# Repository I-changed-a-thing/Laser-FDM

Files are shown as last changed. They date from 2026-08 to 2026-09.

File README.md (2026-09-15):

# Laser FDM + Printer Suite

> ⚠️ **CRITICAL SAFETY & EXPERIMENTAL DISCLAIMER**:  
> This entire software project, hardware integration, and laser-assisted 3D printing pipeline are **100% EXPERIMENTAL** and provided strictly on an **AS-IS, AT-YOUR-OWN-RISK** basis.  
> **All wall smoothing modes can contain software bugs.** Specifically, **Deep Mode** and **all Wobble modes (Deep Wobble & Voxel Wobble)** still contain known bugs with complicated geometries, fine features, sharp overhangs, and non-manifold meshes.  
> High-power laser diodes introduce serious fire, permanent optical radiation (blindness), and toxic fume hazards. Never leave equipment running unattended, maintain proper ventilation, and always wear certified optical safety goggles.  
> **MANDATORY: Always inspect generated G-code in the 3D Simulator or G-Code Visualizer before printing on physical hardware!**
# ⚠️Allways where laser safty glasses⚠️

---

## What This Printer Can Do

This modified Elegoo Neptune 4 uses laser diodes to remelting and modifying the plastic dynamically during the print, it achieves features impossible on a standard printer:

* **+100% Z-Axis Strength Gain:** By pre-heating the previous layer milliseconds before new plastic is laid down (and through structural infill strategies), layer adhesion is dramatically 
* **Glossy, Glass-like Top Surfaces:** The laser does a final glazing pass to melt away top layer extrusion lines.
* **Invisible Z-Seams & Smooth Walls:** Side-mounted lasers remelt the outer perimeters, fusing layer lines together horizontally and vertically for injection-molded quality.
increased.

Here is a glimpse of the data showing the structural strength improvements (comparing standard printing vs. laser-assisted modes):

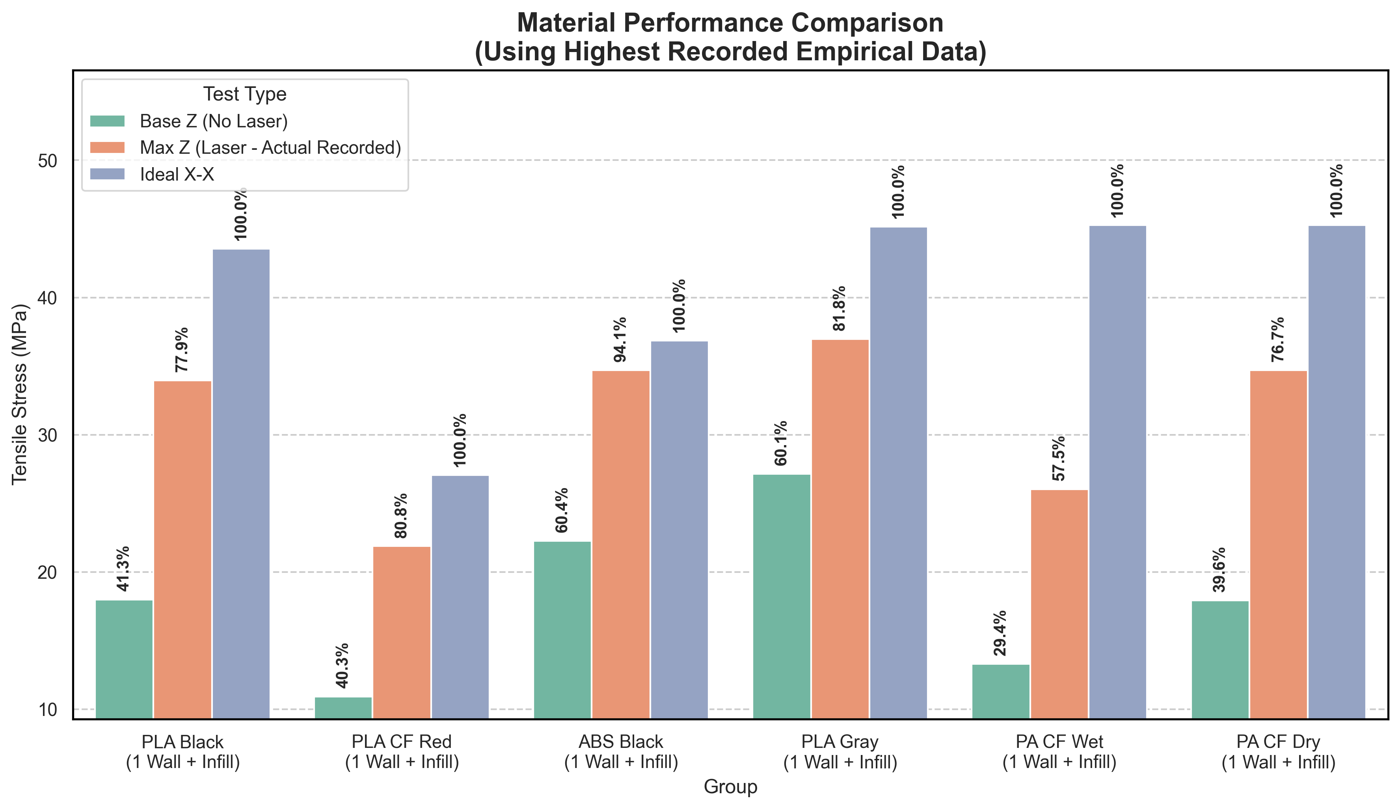
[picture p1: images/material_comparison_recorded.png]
Material Strength Comparison


---

## Video Showcases

See the Laser FDM process in action! 

### Testing Z Axis Strengths 
Testing Z Axis Strengths (https://www.youtube.com/watch?v=Z4Z035srbKI)

### Top Layer smoothing
Laser Smoothness vs Non Laser (https://www.youtube.com/watch?v=vpd5nh9Lj98)

### Wall smoothing
First look at laser FDM printing (https://www.youtube.com/watch?v=qHYnePu4Ysw)

---

## The Hardware Build

*Instructions for building your own Laser FDM printer are detailed in this open-source build guide video.*

Opensource Laser FDM (https://youtu.be/TVKNi_Bk3_o)

---

##  Software Quick Start

1. **Launch the Master Web Portal**:
   - Double-click **`index.html`** right in this folder to open the Laser 3D Printer Suite.
   - It runs completely offline with zero setup or servers required.
   - Use the **Slicer Configurator** to visually configure laser features and generate the exact OrcaSlicer post-processing command.
   
2. **Configure OrcaSlicer**:
   - In OrcaSlicer: **Print Settings** > **Others** > **Post-processing scripts**.
   - Paste the command line generated by the Configurator:
     ```text
     "your_path\python.exe" "your_path\orcaslicer_laser_advanced.py"
     ```
   - When slicing, OrcaSlicer automatically calls the script to inject synchronized laser commands.
   - Use the **G-Code Visualizer** or **3D Toolhead Simulator** to inspect toolpaths layer-by-layer before sending them to your machine.

3. **Printer Firmware (`printer.cfg`)**:
   - Contains reference Klipper output pins (`laser_pwm1`, `laser_pwm2`, `laser_pwm3`) and safety interlocks.

---

## 📂 Release Folder Contents

* **`index.html`**: The main launcher & portal (highest level). Open this in any browser!
* **`web_tools/`**: All web applications:
  * **`configurator/index.html`**: Parameter generator for orcaslicer_laser_advanced.py in Orcalsicer.
  * **`gcode_visualizer/`**: Fast 2D/3D toolpath inspector tool for g-code.
  * **`simulator_3d/`**: G-code toolpath simulation with power heatmaps.
  * **`calibration/index.html`**: Step-by-step guild to calibration wall smoothing offsets.
* **`orcaslicer_laser_advanced.py`**: Production post-processing script for preheating, top surface smoothing, and wall smoothing.
* **`orcaslicer_bricklayer_infill.py`**: Bricklayer infill generator.
* **`orcaslicer_vibrate_infill.py`**: Z-axis infill wave generator script.
* **`printer.cfg`**: Reference Klipper configuration for laser PWM pins.
* **`User_Guide.md`**: Detailed operational guide explaining every single parameter.
* **`Technical_Documentation.md`**: Comprehensive technical architecture and function documentation.

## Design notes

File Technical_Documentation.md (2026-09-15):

# Laser 3D Printer - Technical Documentation

This document provides a comprehensive technical overview of the Laser 3D Printer software stack. It details how the different software components interact, the architecture of the post-processing pipeline, and in-depth descriptions of the functions within each Python script.

---

## 1. System Architecture Overview

The software stack integrates laser processing directly into a standard FDM 3D printing workflow. It intercepts the sliced G-code before it reaches the printer, analyzes the geometric paths (e.g., top surfaces, outer walls), and dynamically injects precise laser control commands. 

The architecture consists of four primary components:
1. **Web Generator UI (`web_generator/index.html`)**: A frontend application that acts as the control panel. Users define their parameters visually, and the UI generates a long, complex command-line string.
2. **OrcaSlicer Post-Processing**: The generated command-line string is pasted into OrcaSlicer's post-processing settings. When a model is sliced, OrcaSlicer automatically runs the Python scripts on the output `.gcode` file.
3. **Python Processing Scripts**: The scripts parse the G-code line-by-line, calculate vectors, cluster geometric shapes, and generate new G-code commands (e.g., `SET_PIN PIN=laser_pwm VALUE=...`) based on the requested features (annealing, smoothing, etc.).
4. **Klipper Firmware (`printer.cfg`)**: The printer's firmware receives the modified G-code. Custom macros and `[output_pin]` configurations execute the laser commands synchronously with the toolhead movements.

---

> ⚠️ **DEVELOPMENT STATUS**: Standard horizontal wall smoothing is the stable production method. All advanced multi-layer wall modes (Deep, Wobble, Voxel Wobble, Voxel Raycast) are in **ALPHA** and must be visually verified before printing on physical hardware.

## 2. Core Post-Processing Script
### `orcaslicer_laser_advanced.py`

This is the primary script responsible for analyzing the G-code and injecting laser commands for preheating, annealing, smoothing, wall remelting. It heavily utilizes 2D vector mathematics and spatial clustering.

#### Geometric & Mathematical Helpers
- **`get_val(line, char)`**: Parses a G-code line (e.g., `G1 X100 Y50 E2 F3000`) and extracts the numeric value following a specific character (e.g., `X`). Returns `None` if missing.
- **`compute_rotated_bbox(points, angle_deg=0.0, margin=0.0)`**: Calculates a rotated bounding box for a set of 2D points to align laser raster paths accurately across irregularly shaped surfaces.
- **`is_touching(ptsA, ptsB, max_dist=3.0)`**: Determines if two sets of points are close enough to be considered a single contiguous shape.
- **`downsample_points(points, resolution=0.5)`**: Reduces the number of points in a path to optimize computation speed.
- **`cluster_points(points, max_dist=2.5)`**: Groups a large set of points into individual, spatially isolated clusters (representing distinct islands or parts on the build plate).
- **`bbox_area(bbox)`**: Calculates the area in mm² of a bounding box.
- **`calculate_boosted_power(base_power, area)`**: Dynamically increases laser power for larger surface areas where heat dissipates more rapidly.

#### Raster & Grid Generation
- **`build_boolean_grid(points, res, max_dist)`**: Creates a 2D boolean occupation grid representing solid areas vs. empty space, used to ensure the laser only fires over the actual printed part and not thin air.
- **`generate_laser_grid(...)`**: The core rasterization engine. It takes a bounding box, an angle, and physical parameters to generate a dense zig-zag pattern of G-code moves across a surface. It handles clipping against the boolean grid, alternating directions, and inserting precise `SET_PIN` commands.
- **`generate_laser_connectivity(...)`**: Similar to the laser grid, but optimized for generating distinct conductive or structural traces.

#### Wall & Path Smoothing
- **`is_point_in_path(pt_x, pt_y, path)`**: Uses ray-casting to determine if a specific point lies inside a closed polygon (used for inner/outer wall sorting).
- **`build_paths_from_segments(segments)`**: Takes chaotic, disconnected line segments and stitches them into continuous, ordered polygons.
- **`split_corners_in_paths(paths, corner_dist, power_scaler, ...)`**: Analyzes paths for sharp corners/angles and dynamically reduces laser power at the apex to prevent overheating and melting the corner away.
- **`generate_wall_smooth_passes(...)`**: Processes outer wall polygons. It calculates perpendicular offsets to position the side-mounted lasers exactly at the focal distance, and handles Z-axis interlacing, multi-height divisions, and temperature drops.
- **`generate_voxel_wobble_passes(...)` & `generate_voxel_raycast_wall_passes(...)`**: Modern slope-adaptive 3D wall smoothing engines. They compute perpendicular offsets, analyze layer-to-layer slope vectors, and apply dynamic apex displacement to follow outer perimeters smoothly.
- **`check_3d_sloped_occlusion(...)`**: Raycasting function that uses the physical diode laser elevation angle (e.g. 22°) to verify line-of-sight and prevent firing through intervening geometry.
- **`generate_wobble_passes(...)`**: Generates high-frequency sinusoidal oscillations along the wall path to broaden the laser melt pool without excessive heat concentration.

#### Parsing & Extraction
- **`will_laser_resume_shortly(...)`**: A look-ahead function that checks upcoming G-code lines to see if the laser will be needed again immediately, preventing unnecessary on/off cycling.
- **`extract_outer_walls(lines)`** & **`extract_top_surfaces(lines)`**: Specialized parsers that scan the raw OrcaSlicer output and extract the exact X/Y coordinates of walls and top layers based on slicing comments.
- **`process_gcode(file_path, args)`**: The main execution loop. It reads the file, tracks the current state (X, Y, Z, E, Feedrate), maintains the active laser configuration, delegates generation to the functions above, and writes the final modified file back to disk.

---

## 3. Mechanical & Infill Manipulation

### `orcaslicer_bricklayer_infill.py`
This script alters internal infill geometry to create staggered, interlocking "brick" patterns that improve structural integrity.
- **`get_val(line, key)`**: G-code parsing helper.
- **`strip_z(line)`**: Removes Z-axis moves from a line to normalize 2D logic.
- **`process_gcode(...)`**: Scans for infill lines and injects retractions and Z-hops to break continuous extrusions into distinct structural "bricks".

### `orcaslicer_vibrate_infill.py`
This script introduces vertical Z-axis oscillations during infill printing to create a 3D corrugated internal structure for enhanced Z-axis strength.
- **`smooth_envelope(d, fade, L)`**: Calculates a mathematical fade-in/fade-out envelope so that the vibrations taper off smoothly near the walls, preventing nozzle collisions with solid perimeters.
- **`process_gcode(...)`**: The main execution loop. It breaks long, flat infill lines into hundreds of microscopic segments, modulating the Z-height of each segment based on a sine wave function `sin(distance / wavelength) * amplitude * envelope`.

---

## 4. Web Ecosystem

### Unified Web Suite (`index.html`)
The release features a unified, responsive Web Suite that runs entirely offline with zero server requirements. A master Hub connects four specialized subpages with persistent cross-navigation:
1. **Configurator & Calibration (`web_tools/configurator/`)**: Generates OrcaSlicer CLI strings, includes JSON preset export/import, Virtual PCB parameters, experimental slicing paths, and Matrix calibration.
2. **G-Code Visualizer (`web_tools/gcode_visualizer/`)**: Fast 2D/3D toolpath inspector with support for hardware Calibration Levels (0 to 4), power heatmaps, and chunk analysis.
3. **3D Toolhead Simulator (`web_tools/simulator_3d/`)**: Photorealistic WebGL simulation featuring the authentic 3D CAD toolhead assembly, cooling fans, golden nozzle, and macro melt-zone camera.
4. **Offset Calibration (`web_tools/calibration/`)**: Step-by-step 10mm cube paper calibration to align angled laser diodes and generate Klipper test macros.
The frontend is built using standard HTML/CSS/JS. It relies on a JavaScript function `generateCommand()` that triggers on any input change. This function dynamically reads all DOM elements, checks for active toggles, and concatenates a formatted string of Python CLI arguments. The UI leverages `localStorage` to save settings between sessions, and implements `JSON.parse`/`JSON.stringify` to export/import complete material preset profiles to the local disk.

### 3D Visualizer (`web_tools/gcode_visualizer/index.html`)
The visualizer uses **Three.js** to render G-code paths in a web browser. It parses standard `G1` moves into lines. More importantly, it specifically searches for the injected `SET_PIN PIN=laser_pwm...` commands generated by the Python scripts. When it detects a laser activation, it changes the color and thickness of the rendered path, interpolating colors from blue (low power) to red (high power), allowing users to visually verify the laser paths and calibration sweeps before running the print.

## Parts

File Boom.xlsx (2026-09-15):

BOM
Part | Link | units | Usecase
Laser Safety glasses for 450nm |  | 1 | To be safe from the lasers
Laser | https://a.aliexpress.com/_EHrgeaE | 2 to 3 | 2 lasers for premelting and 1 for top surface smoothing
ABS | https://www.aliexpress.com/item/1005004961613582.html | 200 g | Material for the Laser holder
12 V 15 A Power supply | https://a.aliexpress.com/_EuvEg3G | 1 | Power the lasers
M2 screws | https://aliexpress.com/item/1005007299422418.html | 4 | Screw in the laser holder into printhead
M3 screws | https://aliexpress.com/item/1005007299422418.html | 12 | Screw in the printer fans
4015 blower fan | https://www.aliexpress.com/item/1005011635639684.html | 1 | Replaces the old small hotend fan
pin connector female | https://a.aliexpress.com/_EjI898i | 3 | Connect the laser to the 3d printer bord pins
Spare cables |  | 3 m | Spare cables to exstand laser lenght

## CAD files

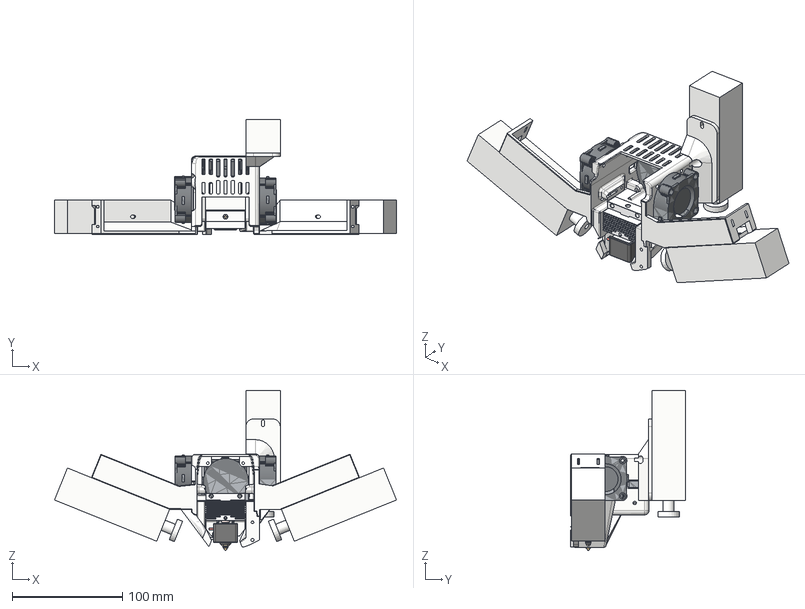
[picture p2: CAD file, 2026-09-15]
CAD/Laser holder.step
310.3 x 103.9 x 145.5 mm
Elegoo Neptune 4 Pro Hotend
PROX2_5_001 (Solid) x 3
Laser 3
Laser x+
Laser x-

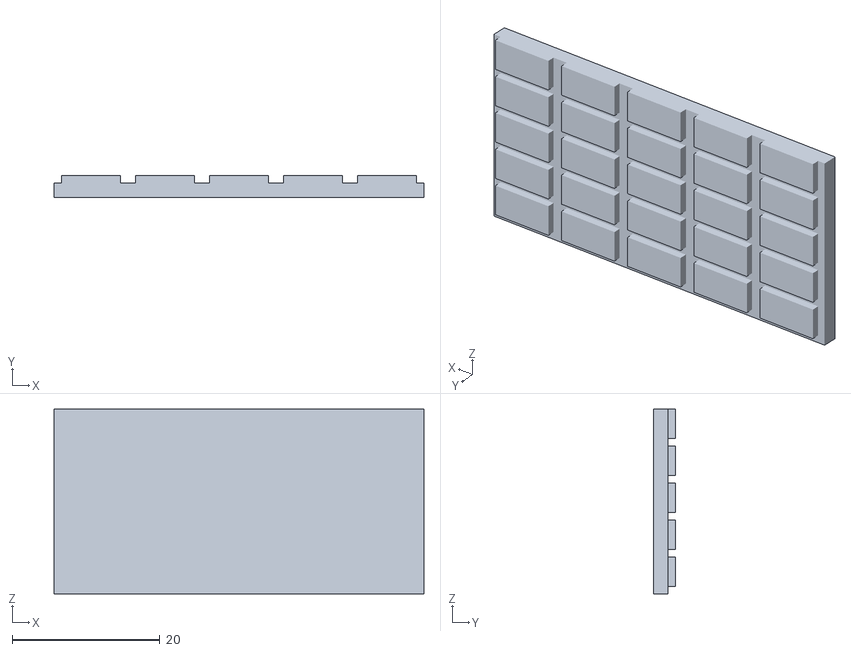
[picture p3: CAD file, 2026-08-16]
Matrix calibration stls/Matrix_Wall_Smoothing.stl
50.0 x 3.00 x 25.0

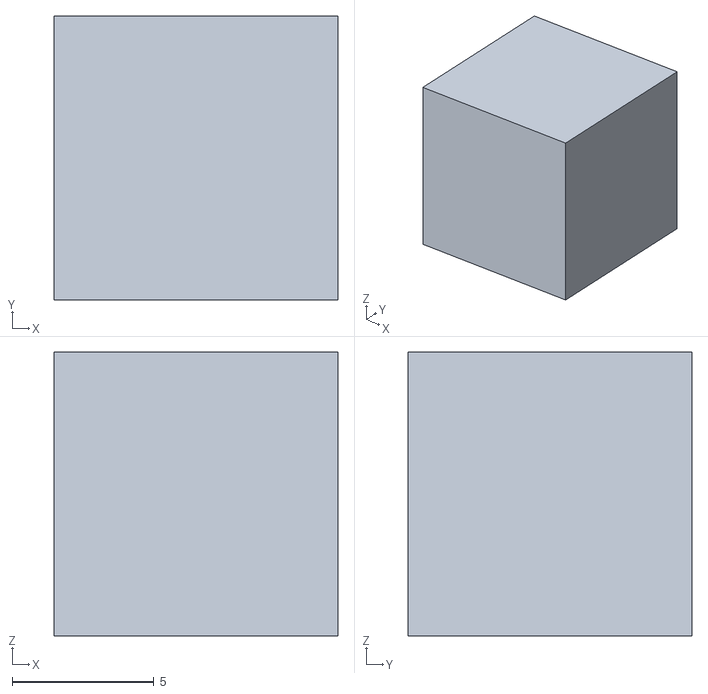
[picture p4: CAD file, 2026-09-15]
web_tools/calibration/models/calibration_cube_10mm.stl
10.0 x 10.0 x 10.0

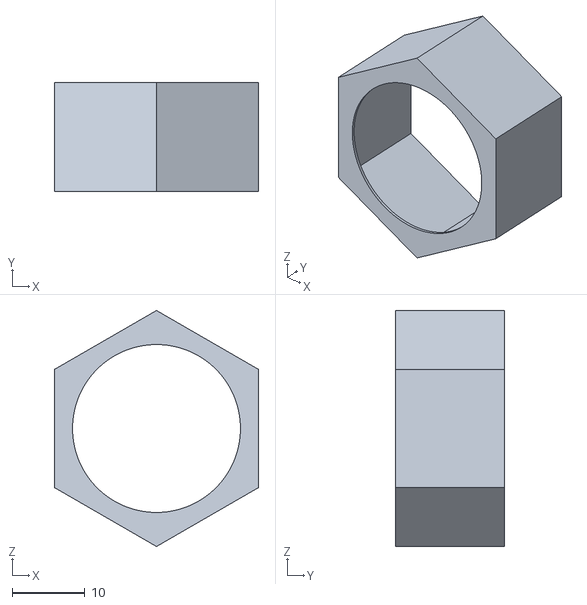
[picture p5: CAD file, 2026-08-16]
Matrix calibration stls/six edege smoothing test.stl
28.0 x 15.0 x 32.3

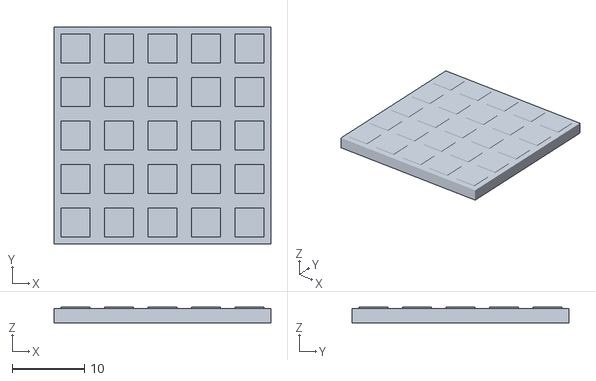
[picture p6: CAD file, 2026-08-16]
Matrix calibration stls/Matrix_Top_Smoothing.stl
30.0 x 30.0 x 2.20

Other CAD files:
CAD/Laser holder.stl

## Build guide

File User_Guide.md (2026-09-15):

# Laser 3D Printer - User Guide

> ⚠️ **IMPORTANT SAFETY & EXPERIMENTAL NOTICE**:  
> The Laser 3D Printer software and hardware stack is **100% EXPERIMENTAL**. All operations are strictly at your own risk.  
> **All wall smoothing modes can contain bugs.** In particular, **Deep Mode** and all **Wobble modes (Deep Wobble & Voxel Wobble)** still have known bugs on complicated shapes, acute overhangs, and fine geometric features.  
> **Always inspect toolpaths in the G-Code Visualizer or 3D Simulator before printing!**

Welcome to the Laser 3D Printer User Guide! This manual explains all the features available in the software, what they actually do to your 3D print, and what every single setting changes so you can get the most out of the script.

---

## 1. Top Surface Smoothing
**What it does:** Once your printer finishes the top layers of a part, it lifts the nozzle slightly and uses a laser to trace a zig-zag pattern over the surface. The heat from the laser gently melts the top layer, reflowing the plastic into a perfectly smooth, glossy finish that hides all extrusion lines.

**Settings:**
*   **Enable:** Turns the feature on or off.
*   **Power:** How strong the laser fires (PWM percentage). Too high causes boiling; too low won't melt the surface.
*   **Speed:** How fast the toolhead moves in mm/s. Slower speeds allow heat to soak deeper.
*   **Grid Spacing:** The distance between the laser zig-zag lines. A smaller spacing (e.g., `0.2mm`) ensures no gaps are left un-melted, but takes longer to print.
*   **Z-Hop:** Lifts the nozzle (e.g., `0.5mm`) so it doesn't drag through the freshly melted plastic while the laser is running.
*   **Overshoot:** The laser will run slightly past the edge of the part before turning around. This prevents the laser from lingering at the edges while the printer decelerates, avoiding burnt corners.
*   **Overshoot Without Laser:** Turns the laser off during the overshoot move so it doesn't fire into thin air.
*   **Passes:** How many times the laser traces the entire surface.
*   **No Alternate:** By default, each pass rotates the zig-zag direction. Enabling this forces all passes to run in the exact same direction.
*   **Angle:** The starting angle (in degrees) of the laser zig-zag pattern.
*   **Angle Step:** How many degrees the pattern rotates on each subsequent pass (default is 90 degrees, creating a crosshatch pattern).
*   **Fan Speed:** Forces the part cooling fan to a specific speed (0-255) during smoothing to cool the plastic immediately after melting.
*   **Preheat Delay:** Forces the laser to turn on and wait in one spot for a few milliseconds before moving, ensuring the start of the line melts properly.
*   **Group Slopes:** Tries to group slanted top surfaces together for smoother continuous sweeps.
*   **Smart Chunking:** If a top surface is too massive, the plastic might warp. This breaks large flat surfaces into smaller "chunks" (e.g., 20mm squares) and smooths them one by one.
*   **Chunk Size:** The maximum size of the chunks in mm.
*   **Chunk No Full Pass:** Disables the final "blending" pass that usually runs over the entire surface to hide the seams between chunks.
*   **Chunk Full Pass Power:** The specific laser power used for that final blending pass.
*   **Area Boost:** Automatically increases laser power on massive surfaces because large areas dissipate heat much faster than tiny spots.
*   **Area Boost (Multiplier):** How much extra power to add at maximum boost (e.g., `0.6` = +60%).
*   **Area Max:** The maximum size (mm²) where the boost hits its ceiling.
*   **Area Base:** The size (mm²) where the script begins gradually applying the boost.

---

## 2. Wall Smoothing
> ⚠️ **IMPORTANT ALPHA NOTICE**:  
> **Standard (Horizontal) mode** is the primary, stable wall remelting technique.  
> All vertical multi-layer modes (**Deep Mode**, **Deep Wobble**, and **Voxel Wobble**) are currently in **ALPHA**. Because they compute complex 3D sweeps across varying layer heights and overhang angles, they are experimental and likely to contain bugs on intricate geometries.  
> **Always inspect your G-code in the G-Code Visualizer or 3D Simulator before printing!**

**What it does:** Layer lines on vertical walls can be unsightly. Wall Smoothing activates side-mounted lasers to trace the outer perimeter of your print, remelting the sides and fusing the layer lines together into a single, smooth surface.

**Settings:**
*   **Enable:** Turns the feature on or off.
*   **Wall Offset Level:** A quick preset to tell the script the X and Z offset distances of your side-mounted lasers.
*   **Custom X+ / X- / Z Offsets:** Exact physical distance from your nozzle to the laser focal point, overriding the level preset.
*   **Power X+ / Power X-:** The laser power for the left and right side lasers.
*   **Overhang Power X+ / X-:** Specific power settings used only when the wall leans outward (an overhang), as they require less power to melt.
*   **Speed:** How fast the toolhead moves along the wall.
*   **Passes:** Number of times the laser traces the wall on a single layer.
*   **Wall Frequency (Layers):** Instead of running every single layer, you can tell it to run every N layers (e.g., every 3 layers).
*   **Target (Both, Inner, Outer):** Which perimeters to smooth. Usually you only want `Outer`.
*   **Min Path Area:** Skips tiny loops (like small bolt holes) where the laser would just sit and burn the plastic.
*   **Angle Tolerance:** Skips walls that lean beyond this angle (aggressive overhangs) to prevent them from drooping.
*   **Corner Power Drop:** Reduces laser power at sharp corners to prevent them from rounding off or melting away.
*   **Corner Distance:** How far from the apex of the corner the power drop begins.
*   **Overshoot:** Extends the wall trace slightly past the start point to ensure the seam is fully melted.
*   **Retract / Max Retract:** Retracts the filament inside the nozzle so it doesn't ooze out while the laser is smoothing the wall.
*   **Standby Temp Drop:** Lowers the hotend temperature temporarily while performing long smoothing operations to prevent filament degradation.
*   **Deep Mode:** Instead of tracing horizontally, the laser pauses and sweeps vertically up and down across multiple layers, deeply fusing a thick vertical chunk.
*   **Z-Divisions:** How many vertical slices to make during Deep Mode.
*   **Deep Overhang Angle:** A stricter angle tolerance for Deep Mode.
*   **Deep Overlap:** How many layers to overlap the vertical sweeps so horizontal seams don't form between chunks.
*   **Deep Safety / Max Layer Safety:** Leaves the very top layers untouched by the deep sweep so the nozzle doesn't collide with them later.
*   **Deep Bottom Up:** Reverses the sweep to start from the bottom and move upward.
*   **Deep Interlace:** Staggers the vertical sweeps to prevent heat from building up in one spot.
*   **Deep Delay Passes:** Waits until the whole wall is done before starting the second pass to allow cooling.
*   **Deep Fade:** Tapers off the power at the very end of a deep sweep to leave a pristine finish.
*   **Wobble Mode:** Rapidly wiggles the laser left/right as it moves along the wall to artificially widen the melt zone without increasing power.
*   **Wobble Projection Factor:** How wide the wiggle should be.
*   **Wobble Pull Only:** Forces the wobble to only happen in directions moving away from the nozzle to prevent crashing into fresh plastic.
*   **Wobble Pull Continuous:** Smooths out the zig-zag into a more continuous wave.
*   **Deep Wobble / Seam Wobble:** Special parameters combining deep vertical sweeps with high-frequency horizontal wiggling for maximum blending.
*   **Pass 2 Mode:** Allows you to run a second, entirely different smoothing strategy immediately after the first pass finishes.
*   **Pass 1 & Pass 2 Modes:**
    *   `Standard`: Traces horizontally along the current layer's outer perimeter (Stable).
    *   `Deep Mode`: Sweeps vertically across multiple layers (Alpha).
    *   `Deep Wobble`: Combines vertical sweeps with horizontal zig-zag oscillation (Alpha).
    *   `Voxel Wobble`: Dynamic slope-adaptive 3D oscillation that follows sloping contours (Alpha).
*   **Wobble X-Scale:** Multiplier to scale the horizontal sweep amplitude to compensate for diode laser beam defocusing.
*   **Adaptive Slope Compensation:** Dynamically shifts the wobble apex outward or inward to match underlying layer overhang angles.
*   **Smart Island Chunking:** Detects when small islands or discrete features end early, triggering smoothing immediately rather than waiting for the entire block.

---

## 3. Experimental Slicing Paths (Bricklayer & Vibration)
**What it does:** Specialized kinematic post-processing tools that operate directly on G-code extrusion and Z movements without firing laser diodes.
## 3. Structural Infill (Bricklayer & Vibration)
**What it does:** Specialized kinematic post-processing tools that operate directly on G-code extrusion and Z movements without firing laser diodes. They alter how your internal infill is printed to make parts stronger.

### Bricklayer Infill (`orcaslicer_bricklayer_infill.py`)
* **Interlocking Extrusion Paths:** Transforms standard 2D infill rasters into a staggered, brick-and-mortar 3D interlock. This dramatically enhances layer-to-layer shear strength and reduces delamination.
Transforms standard 2D infill rasters into a staggered, brick-and-mortar 3D interlock to stop cracks from propagating cleanly through the part.
* **Extrusion Multiplier:** Adjusts flow during bricklaying passes.
* **Retract Length & Z-Hop:** Prevents stringing and collisions during injected travel moves.
* **Retract Length / Speed:** Defines the retraction pulling the filament back between bricks.
* **Z-Hop:** Lifts the nozzle between bricks to prevent stringing.

### Z-Axis Vibration (`orcaslicer_vibrate_infill.py`)
* **Sinusoidal Infill Corrugation:** Oscillates the Z-axis in a fine sinusoidal wave pattern along infill lines. Corrugated vertical ribs create massive structural stiffness while conserving material.
* **Amplitude & Wavelength:** Controls wave height and spacing between peaks.
* **Fade Distance:** Flattens waves near perimeter walls to preserve dimensional accuracy.
Oscillates the Z-axis in a fine sinusoidal wave pattern along infill lines. Corrugated vertical ribs create massive structural stiffness while conserving material.
* **Amplitude:** How high the waves go in mm.
* **Wavelength:** How stretched out the waves are in mm.
* **Spacing:** Distance between parallel lines.
* **Fade Distance:** Flattens waves near perimeter walls to preserve dimensional accuracy and prevent nozzle crashes.
* **Resolution:** How many microscopic segments the straight lines are broken into to create the wave.
* **Sync Phase:** Forces all waves to align perfectly with each other across different lines.

## 4. Preheating
**What it does:** Normally, hot plastic is laid down onto cold plastic, leading to weak bonds. Preheating solves this by firing a laser slightly ahead of the moving nozzle. It pre-melts the surface just milliseconds before the fresh plastic is extruded on top of it, resulting in incredible inter-layer adhesion.

**Settings:**
*   **Enable:** Turns the feature on or off.
*   **Preheat Power:** The base power used. Too high and the plastic will boil.
*   **Reference Speed:** The script automatically scales the laser power based on how fast the toolhead is currently moving. You set the "Reference Speed" (e.g., 50mm/s), and the script calculates everything relative to that.
*   **Min Laser Power:** Hardware minimum limit. If the calculated power drops below this, the laser turns off completely instead of sputtering.
*   **Min Layer:** Skips preheating on the very first few layers.
*   **Trailing Enable:** Activates a second laser located *behind* the nozzle to post-heat the line after it's extruded.
*   **Trailing Ratio:** How strong the trailing laser should be compared to the main preheat laser (e.g., 0.5 = 50% strength).

---

## 5. Annealing
**What it does:** After a layer finishes printing, the laser does a very fast, low-power zig-zag pass over the entire layer. This doesn't melt the plastic, but keeps it warm (in its "crystallization window"). This reduces internal stress, prevents warping, and increases structural strength.

**Settings:**
*   **Enable:** Turns the feature on or off.
*   **Anneal Power:** Must be kept very low. You only want to warm the plastic, not melt it.
*   **Speed:** Usually kept relatively fast to distribute heat evenly.
*   **Spacing:** Distance between the zig-zag lines.
*   **Z-Hop:** Lifts the nozzle so it doesn't drag across the layer.
*   **Overshoot / Overshoot Without Laser:** Extends the path past the edge of the part, optionally turning the laser off during the turn to prevent edge burning.
*   **Min Layer:** Skips annealing on the bottom layers since the heated bed already keeps them warm.
*   **Margin:** Shrinks the annealing path inward from the edge.
*   **Min Area:** Skips annealing on tiny islands.
*   **Angle:** The direction of the annealing zig-zag path.

---

## 6. Structural Infill (Vibration & Bricklayer)
These are special non-laser scripts that alter how your internal infill is printed to make parts stronger.

*   **Z-Axis Vibration:** Rapidly shakes the nozzle up and down while printing infill lines to create corrugated, 3D wave structures inside your part.
    *   **Amplitude:** How high the waves go in mm.
    *   **Wavelength:** How stretched out the waves are in mm.
    *   **Spacing:** Distance between parallel lines.
    *   **Fade:** Gradually flattens the waves near the outer walls so the nozzle doesn't crash into solid perimeters.
    *   **Resolution:** How many microscopic segments the straight lines are broken into to create the wave.
    *   **Sync Phase:** Forces all waves to align perfectly with each other across different lines.

*   **Bricklayer:** Breaks continuous infill lines into staggered, interlocking "bricks" to stop cracks from propagating cleanly through the part.
    *   **Extrusion Multiplier:** Adjusts flow rate for the bricks.
    *   **Retract Length / Speed:** Defines the retraction pulling the filament back between bricks.
    *   **Z-Hop:** Lifts the nozzle between bricks to prevent stringing.

---

## 5. Virtual PCB & Cable Maker Mode
## 6. Virtual PCB & Cable Maker Mode
**What it does:** Allows standard 3D printers to fabricate embedded conductive traces by selectively pyrolyzing and graphitizing carbon-loaded or polymer filaments with the laser diode.

**Settings:**
*   **Enable 2-Pass Mode (`--two-pass`):**
    *   **Pass 1 (Carbonize):** High-energy laser pass to break polymer chains and leave a carbon-rich conductive path.
    *   **Pass 2 (Graphitize / Anneal):** Lower-power, slower secondary pass that crystallizes/graphitizes the carbon path to dramatically reduce electrical resistance.
*   **Pass 1 Power / Speed:** Laser PWM and toolhead speed for initial carbonization.
*   **Pass 2 Power / Speed:** Laser PWM and toolhead speed for the graphitizing annealing pass.
*   **Offset X / Y:** Precise optical offsets from the nozzle tip to the laser focal spot for trace drawing.

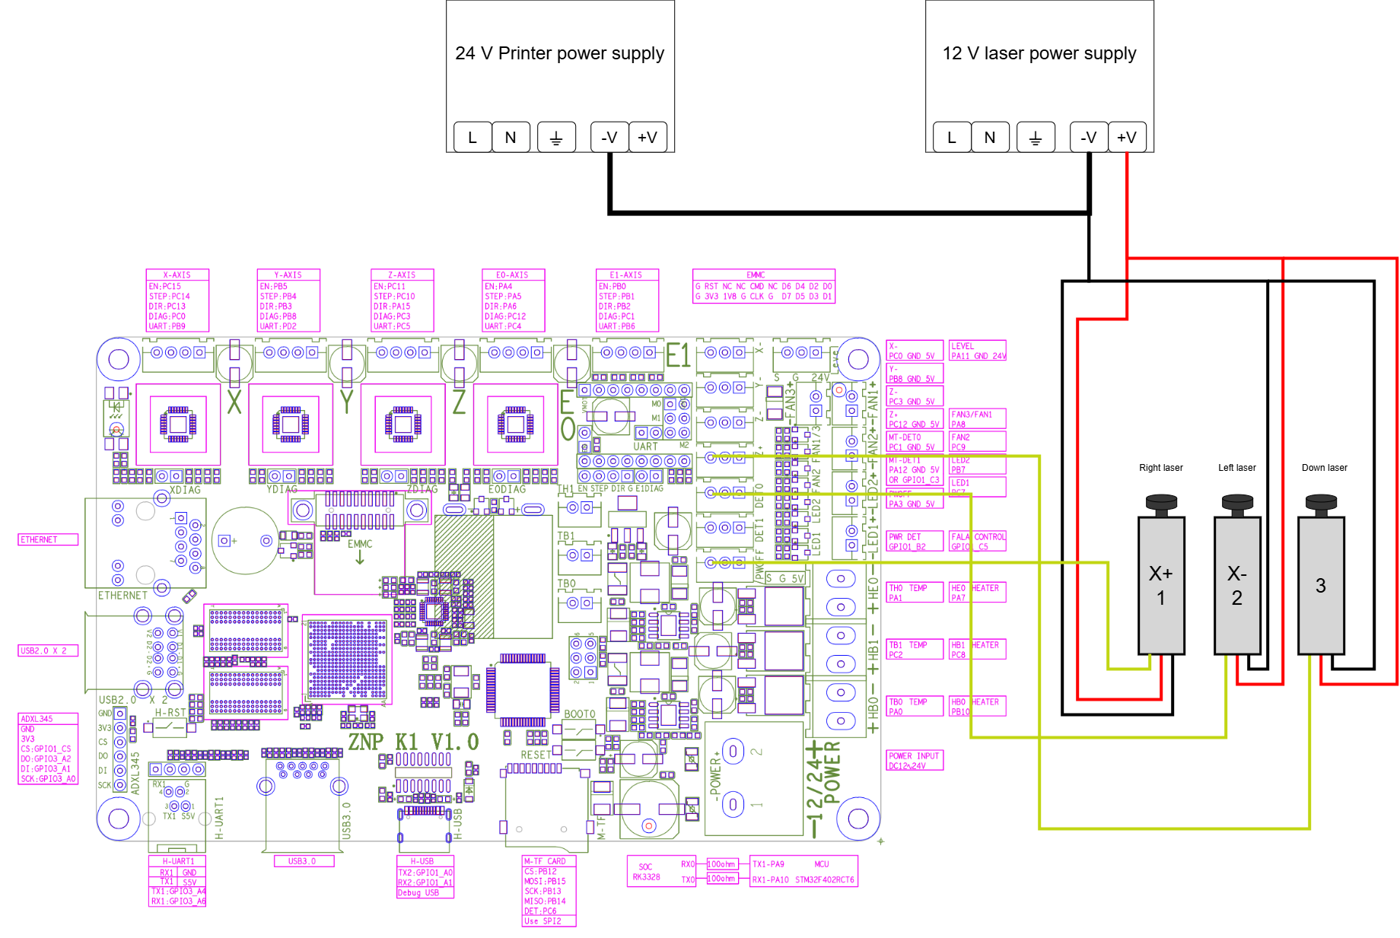
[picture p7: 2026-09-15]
Drawings/Wiring Laser FDM.png

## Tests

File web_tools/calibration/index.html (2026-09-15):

# Laser Diode Offset Calibration

# Laser Wall Offset Calibration

Mounting tolerances can slightly change the true angle of the lasers, which is why we must calibrate them for every machine individually and per laser. Higher offsets might be better for bigger parts to get larger chunk sizes working, though it results in a more defocused beam.

Uncalibrated No default offsets are shipped for safety reasons. Please calibrate the 5 fixed Z standoff heights below.

Download Config File

### Laser Calibration Table

Find your X offsets (Laser 1 and Laser 2) across the 5 default Z heights, or set your own custom height.

Level | Z Standoff | Laser 1 X+ (mm) | Laser 2 X- (mm) | Status

Safety Note: Custom Z standoff must be strictly positive (Z > 0 mm). Zero or negative Z heights are rejected to prevent toolhead collisions.

Save to Browser Hard-Save Config (JSON) Load Config File

Reset / Clear

### Step-by-Step Visual Showcase

Interactive cross-section showing nozzle, paper, 10mm cube, and laser alignment at each step.

Laser 1 (X+) Laser 2 (X-)

1 Print & Remove 2 Home Printer 3 Place Cube 4 Find Z Baseline 5 Align Edge 6 Select Laser 7 Move Z Up 8 Find Offset 9 Save Values

### Calibration Steps

Download 10mm Cube STL

1

#### Print & Remove 10mm Cube

Print the 10x10x10 mm cube. Once done, remove the cube from the bed! Do not home the printer while the cube is on the bed.

2

#### Home Printer (Empty Bed)

Use your printer's menu to home all axes while the bed is completely empty. This ensures the printer finds its zero safely.

3

#### Place Cube Under Nozzle

Move the toolhead up so you can safely place the 10mm cube back onto the bed, directly under the nozzle.

4

#### Find Z Baseline

Place a piece of paper on the cube. Use the printer's menu to slowly lower the nozzle until you feel light friction on the paper. Remove the paper. This is your Z baseline height.

5

#### Align Nozzle to Cube Edge

Move the toolhead using the printer menu until the nozzle tip is perfectly flush with the outer vertical edge of the cube. This position is your X baseline.

6

#### Select Laser & Height

Decide which laser to calibrate first: Laser 1 (Right) or Laser 2 (Left). Choose a Z standoff height from the table (e.g., Level 2 at 10mm).

7

#### Move Z Up & Turn on Laser

Using the printer's menu, move the Z axis up by your chosen standoff height (e.g., move up 10mm). Then, run your printer's laser test macro to turn on the laser at a safe, low power.

8

#### Find the X Offset

Move the toolhead sideways (along the X axis) until the laser spot hits the vertical side wall of the cube. You need to align it so that the exact center of the laser spot rests perfectly on the center of the top layer on that side wall, not the absolute top edge of the part. Note down the distance you moved from your X baseline.

Show Good Alignment Show Bad Alignment

10mm Cube Wall

Correct: The exact center of the laser spot perfectly aligns with the center of the top layer (the middle of the layer's thickness).

9

#### Save Your Values

Enter the X distance into the table. Repeat this entire process for the other laser and for all the standoff heights you want to calibrate. Click Save to Browser and then Hard-Save Config (JSON).

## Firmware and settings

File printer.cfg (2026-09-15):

####################################################################################
# Machine type: NEPTUNE 4
# Current configuration version: V1.4
# Date：2023-12-1
####################################################################################
# This product (Neptune 4/4pro/4plus/4max) adopts Klipper firmware 
# and does not support users to update the official klipper/fluidd
# /moonraker by themselves, otherwise the machine will not work properly.
# If you want to DIY and are an expert or interested in this field, 
# we recommend that you prepare your own tools for burning images so 
# that you can restore them if problems arise. Please contact after-sales 
# support team for tutorials on burning images. Thank you for your cooperation!
####################################################################################
# This file contains common pin mappings for ZNP-K1-V1.0 
# boards. To use this config, the firmware should be compiled for the
# STM32F402. When running "make menuconfig", enable "extra low-level
# configuration setup", select the 32KiB bootloader, and serial (on
# USART1 PA10/PA9) communication.

# The "make flash" command does not work on the ZN-K1-V1.0. Instead,
# after running "make", copy the generated "out/klipper.bin" file to a
# file named "elegoo_k1.bin" on an SD card and then restart the ZNP-K1-V1.0
# with that SD card.

# See docs/Config_Reference.md for a description of parameters.
####################################################################################


[include plr.cfg]

[mcu]
# The hardware use USART1 PA10/PA9 connect to RK3328
serial: /dev/ttyS0
restart_method: command

[stepper_x]
step_pin:PC14
dir_pin:PC13
enable_pin:!PC15
microsteps: 16
rotation_distance: 40
full_steps_per_rotation:200  #set to 400 for 0.9 degree stepper
endstop_pin:PC0
position_min: -6  
position_endstop:-4
position_max: 235
homing_speed:50
homing_retract_dist:5
homing_positive_dir:false

[stepper_y]
step_pin:PB4
dir_pin:PB3
enable_pin:!PB5
microsteps:16
rotation_distance: 40
full_steps_per_rotation:200  #set to 400 for 0.9 degree stepper
endstop_pin:PB8
position_min: -2
position_endstop:0 
position_max:235
homing_speed:50
homing_retract_dist:5
homing_positive_dir:false


[stepper_z]
step_pin:PC10
dir_pin:!PA15
enable_pin: !PC11
microsteps: 16
rotation_distance: 8
full_steps_per_rotation: 200
endstop_pin:probe:z_virtual_endstop ## PB12 for Z-max; endstop have'!' is NO

##  Z-position of nozzle (in mm) to z-endstop trigger point relative to print surface (Z0)
##  (+) value = endstop above Z0, (-) value = endstop below
##	Increasing position_endstop brings nozzle closer to the bed
##  After you run Z_ENDSTOP_CALIBRATE, position_endstop will be stored at the very end of your config
#position_endstop:-5
position_max: 268
position_min: -5 
homing_speed: 8
homing_retract_dist: 5
second_homing_speed: 3

[extruder]
step_pin:PA5
dir_pin:!PA6
enable_pin:!PA4
microsteps:16
rotation_distance: 28.7086  #31.4	#Bondtech 5mm Drive Gears
gear_ratio: 52:10
full_steps_per_rotation: 200	#200 for 1.8 degree, 400 for 0.9 degree
nozzle_diameter: 0.400
filament_diameter: 1.750
min_temp: 0
max_temp: 330
heater_pin: PA7
sensor_type:NTC 100K MGB18-104F39050L32
sensor_pin: PA1
max_power: 1
#control :pid
#pid_kp : 26.213
#pid_ki : 1.304
#pid_kd : 131.721
pressure_advance: 0.020
pressure_advance_smooth_time: 0.01
instantaneous_corner_velocity: 2.5
max_extrude_only_distance: 300
max_extrude_only_velocity:60
max_extrude_only_accel:5000
max_extrude_cross_section: 99
min_extrude_temp:100

[verify_heater extruder]
max_error: 120
check_gain_time:30
hysteresis: 10
heating_gain: 2

[heater_bed]
heater_pin:PB10
sensor_type: NTC 100K MGB18-104F39050L32
sensor_pin: PA0
max_power: 1.0
#control = watermark
min_temp: 0
max_temp: 120


[verify_heater heater_bed]
max_error: 120
check_gain_time:120
hysteresis: 10
heating_gain: 2



[respond]
default_type: echo
default_prefix: echo:

[virtual_sdcard]
path: ~/gcode_files
on_error_gcode: 
    # test OK
    G91
    G1 Z25 F900
    G90
    TURN_OFF_HEATERS
    M106 S100
    M84
    M300 P10000 S1
    G4 P300
    M300
    M300
    M300
    M300
    M300
    M300
    M300
    M300
    M300
    M300
    M300

########################################
# PRINT_START/CANCEL_PRINT/PAUSE/RESUME/filament_switch_sensor
########################################

[print_stats]

[gcode_move]

    
[gcode_macro PRINT_START]         
gcode:
    SAVE_VARIABLE VARIABLE=was_interrupted VALUE=True
	  G92 E0                                         
	  G90             
    CLEAR_PAUSE
    M117 Printing                   
    
[gcode_macro PRINT_END]
gcode:
    LASER_OFF
    SAVE_VARIABLE VARIABLE=was_interrupted VALUE=False
    RUN_SHELL_COMMAND CMD=clear_plr
    clear_last_file
    {% set RUN_VELOCITY = printer.configfile.settings['printer'].max_velocity|float %}
    {% set RUN_ACCEL    = printer.configfile.settings['printer'].max_accel|float %}
    {% set RUN_DECEL    = printer.configfile.settings['printer'].max_accel_to_decel|float %}
    SET_VELOCITY_LIMIT VELOCITY={RUN_VELOCITY} ACCEL={RUN_ACCEL} ACCEL_TO_DECEL={RUN_DECEL}
    M220 S100
    M221 S100
    {% set z = params.Z|default(100)|int %}
    {% if (printer.gcode_move.position.z+5) < z %}
    G90 							            ; absolute positioning
    G1 Z{z+5} F6000 				      ; park nozzle at rear
    {% endif %}
    TURN_OFF_HEATERS
    M107
    M84


[gcode_macro CANCEL_PRINT]
rename_existing: BASE_CANCEL_PRINT
gcode:
      LASER_OFF
      SAVE_VARIABLE VARIABLE=was_interrupted VALUE=False
      RUN_SHELL_COMMAND CMD=clear_plr
      clear_last_file
      {% set RUN_VELOCITY = printer.configfile.settings['printer'].max_velocity|float %}
      {% set RUN_ACCEL    = printer.configfile.settings['printer'].max_accel|float %}
      {% set RUN_DECEL    = printer.configfile.settings['printer'].max_accel_to_decel|float %}
      SET_VELOCITY_LIMIT VELOCITY={RUN_VELOCITY} ACCEL={RUN_ACCEL} ACCEL_TO_DECEL={RUN_DECEL}
      {% set z = params.Z|default(100)|int %}  
      {% set x_park = params.X|default(printer.toolhead.axis_minimum.x+5)|int %} 
      {% set y_park = params.Y|default(printer.toolhead.axis_maximum.y-5)|int %} 
      SET_IDLE_TIMEOUT TIMEOUT={printer.configfile.settings.idle_timeout.timeout} 
      SDCARD_RESET_FILE
      M400
      M220 S100
      M221 S100
      G91
      M83
      G1 E-10.0 F1200
      TURN_OFF_HEATERS
      M107
      {% if (printer.gcode_move.position.z+5) < z %}
      G90
      G0 X{x_park} Y{y_park} Z{z+5} F6000
      {% endif %}
      {%if (printer.gcode_move.position.z+5) >= z %}
      {%if (printer.gcode_move.position.z+5) < printer.toolhead.axis_maximum.z %}
      G91
      G1 Z5 F300
      G90
      G0 X{x_park} Y{y_park} F6000
      {% else %}
      G90
      G0 X{x_park} Y{y_park} Z{printer.toolhead.axis_maximum.z} F6000
      {% endif %}
      {% endif %}
      M84

[pause_resume]
recover_velocity: 50.0 

[gcode_macro PAUSE]
rename_existing: BASE_PAUSE
gcode:
    LASER_OFF
    M400 
    {% set z = params.Z|default(30)|int %}                                                   
    {% set E = (params.E|default(2))|float %}
    {% set x_park = params.X|default(printer.toolhead.axis_minimum.x+5)|int %} 
    {% set y_park = params.Y|default(printer.toolhead.axis_maximum.y-5)|int %} 
                                                                                  
    {% if (printer.gcode_move.position.x) <= (x_park+1) and (printer.gcode_move.position.y) >= (y_park-1) %}
      M400
    {% else %}
      {% set position = printer.gcode_move.gcode_position %}
        SET_GCODE_VARIABLE MACRO=RESUME VARIABLE=saved_x VALUE="{position.x}"
        SET_GCODE_VARIABLE MACRO=RESUME VARIABLE=saved_y VALUE="{position.y}"
        SET_GCODE_VARIABLE MACRO=RESUME VARIABLE=saved_z VALUE="{position.z}"
        SET_GCODE_VARIABLE MACRO=RESUME VARIABLE=saved_e VALUE="{E}"
        SET_GCODE_VARIABLE MACRO=RESUME VARIABLE=etemp VALUE={printer['extruder'].target}   
        SET_GCODE_VARIABLE MACRO=RESUME VARIABLE=bed_temp VALUE={printer['heater_bed'].target}   
        SAVE_GCODE_STATE NAME=timelapse_state_a
        M83
        G91
      {% if (printer.gcode_move.position.z+5) <  printer.toolhead.axis_maximum.z  %}
        G1 E-2 X3 Z1 F2100
        G1 Z4 F600
      {% endif %}
        SAVE_GCODE_STATE NAME=timelapse_state_b
        G90
      {% if (printer.gcode_move.position.z+5) < z %}
        G1 Z{z+5} X{x_park} Y{y_park} E-20 F6000 
      {% else %}
        G1 X{x_park} Y{y_park} E-20 F6000
      {% endif %}
        M400
        M25
        SET_IDLE_TIMEOUT TIMEOUT=1200
        M400
    {% endif %}
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

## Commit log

2026-08-16 Inital commit
    [Matrix_Rivet.stl, Matrix_Top_Smoothing.stl, Matrix_Wall_Smoothing.stl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]
2026-09-15 Delete laser_visualizer directory
    Update Webtools
2026-09-15 Update for V0.1
    removing all non-ready parts
    [Boom.xlsx, Laser holder.step, Laser holder.stl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]
2026-09-15 Update Boom
    [Boom.xlsx]
